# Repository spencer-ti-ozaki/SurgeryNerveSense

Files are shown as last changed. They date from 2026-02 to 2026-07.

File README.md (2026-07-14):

# NerveSense

**NerveSense** is a surgical proximity device designed to help surgeons detect and avoid peripheral nerves during incision. It estimates the distance between a surgical probe and a nearby nerve in real time, displaying the result on an LCD screen. Link for demo video: https://youtu.be/kSlPQVkup6I

> **Disclaimer:** NerveSense is a proof-of-concept prototype developed as a university engineering project. It is not approved for clinical use, and has only ever been tested on a tissue phantom with a controlled nerve analog — never on a live nerve or living tissue. See [TESTING.md](TESTING.md).

### Documentation

| File | What's in it |
|---|---|
| **README.md** | Overview, subsystems, hardware (this file) |
| [THEORY.md](THEORY.md) | Operating principle & the physics of the distance estimate |
| [TESTING.md](TESTING.md) | **How it was validated** — nerve analog, tissue phantoms, data, results, scope |
| [RESEARCH.md](RESEARCH.md) | Open questions & next experiments (for collaborators / follow-on work) |
| [USAGE.md](USAGE.md) | Step-by-step operating instructions |
| [WIRING.md](WIRING.md) | Full wiring reference and pinout |

---

## The Problem

Peripheral nerve injuries (PNIs) affect 13–23 people per 100,000 annually in the US, with 8–25% caused directly by medical procedures. Full recovery occurs in only 5.1% of cases. Current nerve-detection technologies (ultrasound, IONM, fluorescent markers) lack real-time, unambiguous proximity sensing — NerveSense addresses this gap.

---

## How It Works

NerveSense is divided into four subsystems: **Signaling → Receiving → Calculating → Displaying.**

```
┌─────────────────────────────────────────────────────────┐
│                    NerveSense System                    │
│                                                         │
│  [TENS Pads] ──► [L298N Driver] ──► Stimulates tissue  │
│       ▲                                    │            │
│  12V Boost                         Compound Action      │
│  (XL6009)                          Potential (CAP)      │
│                                            │            │
│  [Scalpel Electrode (S+)] ◄────── tissue response       │
│  [Reference Electrode (S-)]                │            │
│            │                               │            │
│            └──────► [AD620 Amplifier] ─────┘            │
│                          │ (100x gain)                  │
│                          ▼                              │
│                  [Raspberry Pi Pico]                    │
│                  ADC reads voltage                      │
│                          │                              │
│                          ▼                              │
│                   Distance calculation                  │
│                   d = 20 × e^(−7.21 × ΔV)              │
│                          │                              │
│                          ▼                              │
│                    [20×4 LCD Display]                   │
│             Row 1: Proximity warning                    │
│             Row 2: Distance (cm)                        │
│             Row 3: Voltage                              │
│             Row 4: Delta Voltage                        │
└─────────────────────────────────────────────────────────┘
```

---

### 1. Signaling

Two **TENS unit electrode pads** are placed on the patient's skin over the surgical site. An **L298N motor driver** switches these pads on and off at **20 Hz** — the clinically established frequency for eliciting a Compound Action Potential (CAP) from a nerve. A **XL6009 DC-DC boost module** steps the supply up to **12V** to compensate for the ~40% voltage drop across the pads and skin, ensuring at least 5V reaches the tissue.

A **grounding electrode** was added to the signaling unit to prevent charge buildup in the tissue (which would otherwise behave like a capacitor and corrupt the signal).

### 2. Receiving

When a stimulated nerve fires, it produces a CAP — an AC electrical response with a peak voltage of ~100mV — that spreads outward through the surrounding tissue (volume conduction). The **scalpel probe (S+)** and a **reference electrode (S-)** measure the resulting voltage difference at the surgical site; the closer the probe is to the nerve, the larger the reading. (In bench testing this firing nerve was replaced by a controlled **nerve analog** — see [TESTING.md](TESTING.md) — and the physics of why amplitude encodes distance is in [THEORY.md](THEORY.md).)

Because 100mV is too weak for the Pico's ADC to read directly, the signal passes through an **AD620 instrumentation amplifier module** at a gain of 100×. A custom PCB with an INA333 amplifier and bandpass filter was also designed (using Altium Designer) to isolate the nerve's 20Hz signal — see `/PCB` for design files.

> **PCB Note:** The custom INA333 PCB is a more robust alternative to the AD620 module due to its integrated bandpass filter, which actively filters out non-nerve frequencies and reduces noise. However, if using the PCB, the RG resistor should be swapped to a **100 Ω resistor** to set the correct gain for this application. Additionally, the PCB in its present state includes **no voltage protection** — adding a clamping circuit or protection resistors before any further use is strongly recommended.

The electrodes are made from **silver wire coated in AgCl** (via reaction with bleach) to minimize capacitive interference — bare stainless steel was found to convert the tissue analogue into a capacitor, skewing readings.

### 3. Calculating

The Raspberry Pi Pico reads ADC samples every millisecond and computes:

- **`baseline`** — mean ADC reading captured at startup, with the device at rest (calibration period)
- **`avg_diff_volts`** — average voltage deviation from baseline over each 250ms window

Distance is estimated using an empirically derived exponential curve fitted to 10 data points (R² = 0.9321):

```
d = 20 × e^(−7.21 × avg_diff_volts)
```

The constants were fit on a tissue phantom; a separate physics-first (analytical) derivation gives the same exponential *shape* — both are documented in [THEORY.md](THEORY.md), and the calibration data behind them in [TESTING.md](TESTING.md).

**Proximity thresholds used for display warnings:**

| `avg_diff_volts` | Display Message |
|---|---|
| > 0.40 V | Close to Nerve |
| > 0.25 V | Medium to Nerve |
| > 0.10 V | Far to Nerve |
| ≥ 5V or 0V | Outside of Site |

### 4. Displaying

A **20×4 I2C LCD** shows:
- **Row 1:** Proximity warning (e.g., "Close to Nerve")
- **Row 2:** Distance in cm
- **Row 3:** Current voltage reading
- **Row 4:** Delta voltage (`avg_diff_volts`)

---

## Validation Summary

NerveSense was characterized on a **tissue phantom** (chicken breast, and agar/saline
gel) with a **nerve analog** (a copper wire driven at 110 mV / 20 Hz pulsed DC to
mimic a real ~100 mV CAP). It has **not** been tested on a live nerve.

| Metric | Result |
|---|---|
| Detection range | ~5 cm from the nerve analog |
| Distance accuracy | ±0.5 cm (0–5 cm range) |
| Empirical fit | R² = 0.9321 (10 calibration points) |
| Reliability | ~10% of samples show voltage spikes |

Full methodology, scope, and what this does/doesn't prove: **[TESTING.md](TESTING.md)**.

---

## Hardware Components

| Component | Role |
|---|---|
| Raspberry Pi Pico | Microcontroller / ADC |
| L298N Motor Driver (×2) | Nerve stimulation + testing |
| XL6009 DC-DC Boost | Step up to 12V for signaling |
| AD620 Amplifier Module | 100× signal amplification |
| 20×4 I2C LCD | Distance/voltage display |
| TENS Unit Contact Pads | Stimulating electrodes |
| Skintact Electrode Pads (×3) | Receiving electrodes |
| AgCl-coated Silver Wire | Low-capacitance electrode material |
| Custom PCB (INA333) | Bandpass filter + amplifier (see `/PCB`) |

---

## Repository Structure

```
SurgeryNerveSense/
├── CAD/              # STEP files for the scalpel probe, frame, lid, and enclosure
├── PCB/              # PCB design files (Altium), DWG, and design rule check
├── Code/             # MicroPython firmware for the Raspberry Pi Pico
├── README.md         # This file — overview
├── THEORY.md         # Operating principle & physics
├── TESTING.md        # Validation methodology, data, and results
├── RESEARCH.md       # Open questions & next experiments
├── USAGE.md          # Step-by-step operating instructions
└── WIRING.md         # Wiring reference and pinout
```

---

## Limitations & Future Work

- Requires recalibration for different tissue types
- ~10% of samples exhibit voltage spikes
- AgCl electrode coating degrades under sunlight and requires bleach re-coating between uses
- No emergency shut-off or voltage protection circuit

**Suggested future improvements:**
- Replace AD620 with INA333 + proper bandpass filter PCB
- Add voltage protection and emergency shut-off
- Improve UI for clinical accessibility

For the bigger research questions (testing on a real nerve, lock-in detection for
selectivity, calibration transfer) and proposed next experiments, see
**[RESEARCH.md](RESEARCH.md)**.

---

## Team

Developed by **Kona Burgess, Spencer Ozaki, Shreya Chellu, and Rui (Ryan) Geng** as part of the Cornerstone of Engineering II course at Northeastern University London (Spring 2026).

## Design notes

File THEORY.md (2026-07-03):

# NerveSense — Operating Principle & Theory

This document explains *why* NerveSense should work in principle, the physics
behind the distance estimate, and the assumptions that estimate rests on. For
how it was actually tested, see [TESTING.md](TESTING.md).

---

## 1. The intended biological mechanism

NerveSense is a **stimulate-and-record** proximity sensor:

1. **Stimulate.** TENS pads deliver a 20 Hz pulse train to the tissue around the
   surgical site. Clinical work shows ~20 Hz at a few volts of contact drive is
   sufficient to elicit a **compound action potential (CAP)** from a peripheral
   nerve (Ahn et al., 2025).
2. **Re-radiate.** A firing nerve is, electrically, a **propagating current
   source** inside a conductive volume (tissue). It sets up a potential field
   that spreads outward through the surrounding medium (volume conduction).
3. **Record.** A scalpel-mounted electrode (S+) and a distant reference (S−)
   measure the local potential of that field. The **closer the probe is to the
   nerve, the larger the recorded potential.**
4. **Convert.** Amplitude → distance via a calibrated curve.

The signal of interest is **phase-locked to the 20 Hz stimulus**, which in
principle separates "the nerve we are driving" from unrelated tissue noise.

---

## 2. Why amplitude encodes distance

In a conductive medium, the potential from a current source falls off with
distance from that source. The device leans on this monotonic relationship:
more voltage at the probe ⇒ closer to the source.

### Analytical sketch (the physics-first derivation)

Model the path between source and probe as a conductor whose resistance depends
on geometry:

```
R = ρ · L / A
```

- `ρ` — resistivity of the tissue (inverse of conductivity σ; muscle ≈ 0.15 S/m
  across-fiber)
- `L` — effective path length between source and probe (∝ distance)
- `A` — effective cross-sectional area of the conduction path

By Ohm's law the potential seen at the probe scales with this path resistance
for a given source current, and the instrumentation amplifier multiplies the
result by its gain `G`:

```
V_probe(measured) = G · I_source · R(L)  =  G · I_source · ρ · L / A
```

Because the *effective* `A` grows as the field spreads with distance while `L`
also grows, the measured amplitude **decays** as the probe moves away — and the
decay is steeper than linear, which is why an **exponential** fits the data far
better than a straight line. The full closed form (with the geometric
assumptions) is Appendix E of the project report.

> The analytical model gets the **shape** right but depends on `ρ`, geometry,
> and gain that are hard to pin down in messy tissue — which is why the shipped
> firmware uses the **empirical** fit instead (below).

### Empirical model (what actually ships)

```
d = 20 · e^(−7.21 · avg_diff_volts)          (d in cm)      R² = 0.9321
```

Fit to 10 measured (distance, voltage) points in a tissue phantom. See
[TESTING.md](TESTING.md) §5.

---

## 3. Signal conditioning (why the hardware looks the way it does)

The raw CAP is ~100 mV — far too small for the Raspberry Pi Pico's ADC and
buried in noise. The receive chain addresses this:

- **AD620 instrumentation amplifier, ×100** — measures the *difference* between
  S+ and S− (rejecting common-mode noise) and boosts it into the Pico's
  readable range.
- **Custom INA333 PCB + bandpass filter (alternative front end)** — designed to
  additionally reject everything outside the 20 Hz stimulation band. It needs a
  small DC bias to activate (the amplifier only turns on above ~0.1 V), solved
  with a voltage divider + 2.5 V pull-up. It ran reliably for ~3 weeks before
  both boards were destroyed; the AD620 module was the fallback for the demo.
- **AgCl-coated silver electrodes** — a bare stainless-steel electrode
  polarizes and turns the tissue interface into a **capacitor**, distorting the
  reading. Ag/AgCl is the standard **non-polarizable** bioelectrode; we made ours
  by coating silver wire via a bleach reaction.
- **Grounding electrode on the stimulator** — continuously discharges the tissue
  so the stimulus doesn't slowly charge the phantom like a capacitor.

---

## 4. Key assumptions (and where they can break)

| Assumption | Holds when… | Breaks when… |
|---|---|---|
| Source behaves like a clean line current source | Nerve fires synchronously to the stimulus | Weak/desynchronized firing; multiple nerves |
| Medium is roughly homogeneous & isotropic near the probe | Uniform phantom | Real tissue: fat/vessel/bone boundaries, anisotropy |
| Amplitude maps 1:1 to distance | Fixed source strength & geometry | Different nerve caliber/orientation → same amplitude, different distance |
| Calibration constants are valid | Same tissue type as calibration | New tissue conductivity → curve shifts (needs recalibration) |

These are exactly the questions a research collaboration would tackle — see
[RESEARCH.md](RESEARCH.md).

---

## 5. How this differs from existing nerve monitors

Commercial intraoperative systems (e.g. NuVasive/Globus NVM5, Medtronic NIM)
and stimulating dissectors work by **stimulating from the instrument and
recording the downstream muscle EMG** — proximity is inferred from the stimulus
current needed to evoke a twitch. NerveSense instead **stimulates proximally and
records the CAP directly at the probe.** That distinction is the potentially
novel part: it does not depend on an intact motor pathway or neuromuscular
junction, so in principle it could apply to sensory nerves and to nerves whose
target muscle isn't accessible. Whether that theoretical advantage survives
contact with a real nerve is the open research question.

---

## References

- Ahn, H.-Y., et al. (2025). *Bioresorbable, wireless dual stimulator for
  peripheral nerve regeneration.* Nature Communications 16(1).
  https://doi.org/10.1038/s41467-025-59835-7
- Zelenski, N.A., Oishi, T., Shin, A.Y. (2023). *Intraoperative Neuromonitoring
  for Peripheral Nerve Surgery.* J Hand Surg 48(4), 396–401.
  https://doi.org/10.1016/j.jhsa.2022.11.022

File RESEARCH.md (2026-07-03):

# NerveSense: Research Directions and Open Questions

*A brief for researchers evaluating NerveSense as a basis for further work.*

## Summary

NerveSense estimates the distance from a surgical probe to a peripheral nerve by
stimulating the nerve and recording its compound action potential (CAP) directly
at the probe, then mapping the recorded amplitude to distance. On a tissue
phantom driven by a controlled nerve analog, a ten-point empirical fit predicts
distance to within 0.5 cm over a 0 to 5 cm range (R² = 0.93) and produces a
real-time, unambiguous readout. The sensing physics has been demonstrated on the
bench. The two questions that determine whether the approach is clinically
meaningful, whether the relationship holds for a real excitable nerve and whether
the signal can be made selective, remain open and are the natural starting point
for a collaboration.

## Novelty

Existing intraoperative systems infer nerve proximity indirectly. Devices such as
the NuVasive/Globus NVM5, the Medtronic NIM, and stimulating dissectors deliver a
stimulus from the instrument and record the downstream muscle EMG; proximity is
read from the stimulus current required to evoke a twitch. That approach depends
on an intact motor pathway and neuromuscular junction, and it reports a muscle
response rather than a direct measurement at the tool.

NerveSense reverses the arrangement. Stimulation is applied proximally through
surface pads, and the CAP is recorded directly at the probe as a graded,
distance-dependent potential. Because the measurement is taken at the instrument
rather than at a muscle, the method does not require a motor endpoint, which in
principle extends it to sensory nerves and to nerves whose target muscle is
inaccessible. Recovering a continuous distance estimate from CAP amplitude, as
opposed to a binary "stimulus threshold crossed" signal, is the aspect most worth
investigating. Whether the graded relationship survives a biological source at
realistic signal levels is the central unknown.

## Established versus open

| Established on phantom | Open |
|---|---|
| Monotonic, fittable voltage-to-distance falloff in real tissue | Same behavior with a real excitable nerve as the source |
| 0.5 cm accuracy over 0 to 5 cm at calibrated conditions | Adequate SNR at a ~100 mV CAP through millimeters of real tissue |
| Real-time, unambiguous readout | Selectivity of the nerve against vessels and other conductors |
| Ag/AgCl electrodes and a grounding pad suppress capacitive artifacts | Transfer of the calibration across tissue types |

The full scope boundary is documented in [TESTING.md](TESTING.md).

## Proposed next experiments

1. Replace the copper nerve analog with a real nerve preparation. A frog sciatic
   nerve is the standard low-cost option, with an ex-vivo mammalian nerve as the
   next step. Repeating the distance-to-amplitude characterization on a
   biological source, and confirming whether the exponential relationship and the
   SNR both hold, is the single most informative test and the main capability a
   host lab's electrophysiology rig unlocks.
2. Add synchronous (lock-in) detection at the 20 Hz stimulation frequency. Only
   the stimulated nerve re-radiates in phase with the stimulus, so phase-sensitive
   detection should improve both SNR and selectivity, and stands on its own as a
   methods result. The current firmware reads raw amplitude only.
3. Quantify calibration drift across media. Running the protocol across agar
   batches of known conductivity (0.05 to 0.5 S/m) and across tissue types would
   measure how far the fitted constants move, and whether a normalization or
   self-calibration step removes the need to recalibrate per tissue.
4. Address amplitude ambiguity. A multi-electrode gradient probe, or the use of
   CAP latency rather than amplitude alone, could separate a small near source
   from a large far one.
5. Move to a medical-grade front end. The INA333 PCB with proper bandpass
   filtering, voltage protection, and an emergency shut-off is a prerequisite
   before any work involving a living subject.

## Prior art

- Triggered-EMG proximity systems: NuVasive/Globus NVM5 and Medtronic NIM.
- Patents on nerve-proximity instruments, including a scalpel with an integrated
  nerve sensor (US 5,928,158) and nerve proximity, direction, and pathology
  systems (US 9,931,077 and its family).
- Intraoperative neuromonitoring reviews (Zelenski et al., 2023) and
  peripheral-nerve stimulation parameters (Ahn et al., 2025).

Nerve-proximity sensing as a general goal is well established and patented. The
contribution here is the direct-CAP-recording mechanism and its quantitative
characterization, which the prior art does not cover in this form.

## Collaboration

The project provides a working, documented, low-cost bench prototype, spanning
hardware, firmware, CAD, and PCB, that already yields clean distance-to-voltage
data, together with a tightly scoped first experiment and a self-contained
methods angle in the lock-in approach. Advancing it draws on capabilities a host
lab is positioned to provide: an electrophysiology setup, nerve-preparation
protocols, and the ethics and tissue-use approvals required to test on a real
nerve.

*Maintained by the NerveSense team (Northeastern University London). Contact
details are in the repository and project report.*

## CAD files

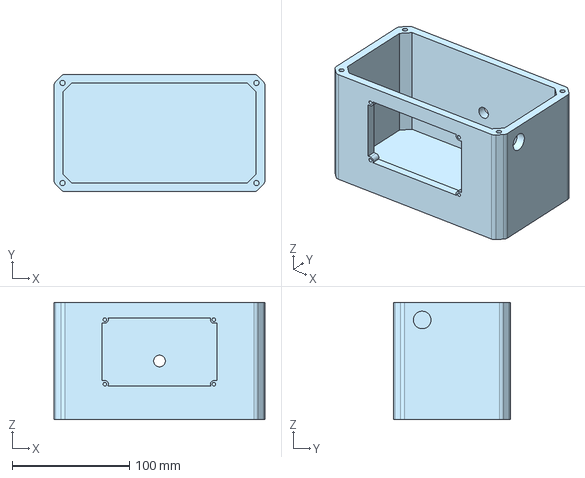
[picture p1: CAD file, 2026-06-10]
CAD/NerveSense-Frame.step
180.0 x 100.0 x 100.0 mm

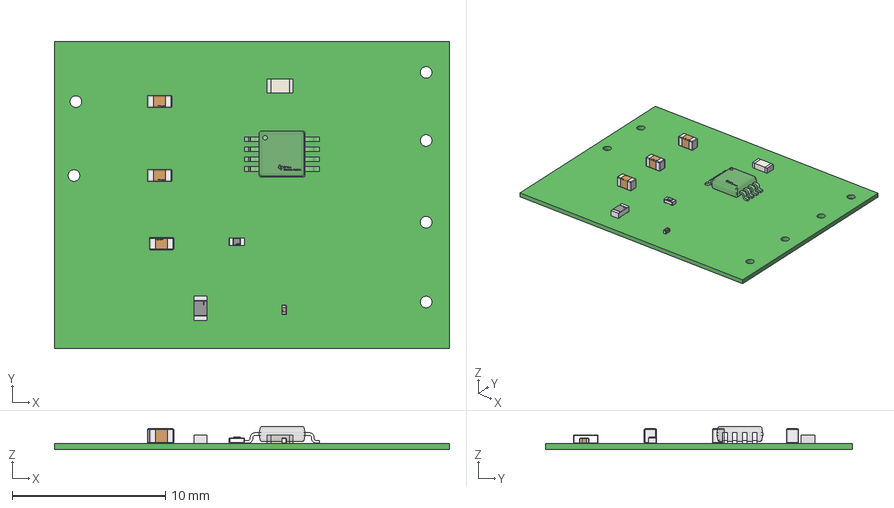
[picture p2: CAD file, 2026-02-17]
PCB/NerveSensePCBv0.2.1.step
25.8 x 20.1 x 1.51 mm
terminals x 5
logo x 5
BODY_MUA08A
LEAD_MUA08A x 8
Texas Instruments
circle
Extruded x 3
top
Sides
Core
Top
Vishay Logo

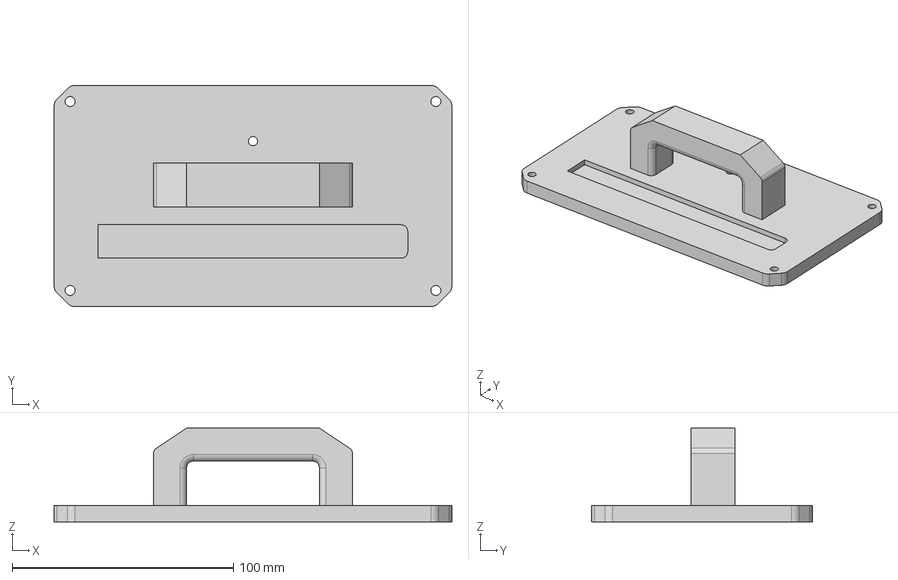
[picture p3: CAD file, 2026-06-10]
CAD/NerveSense-Lid.step
180.0 x 100.0 x 42.5 mm

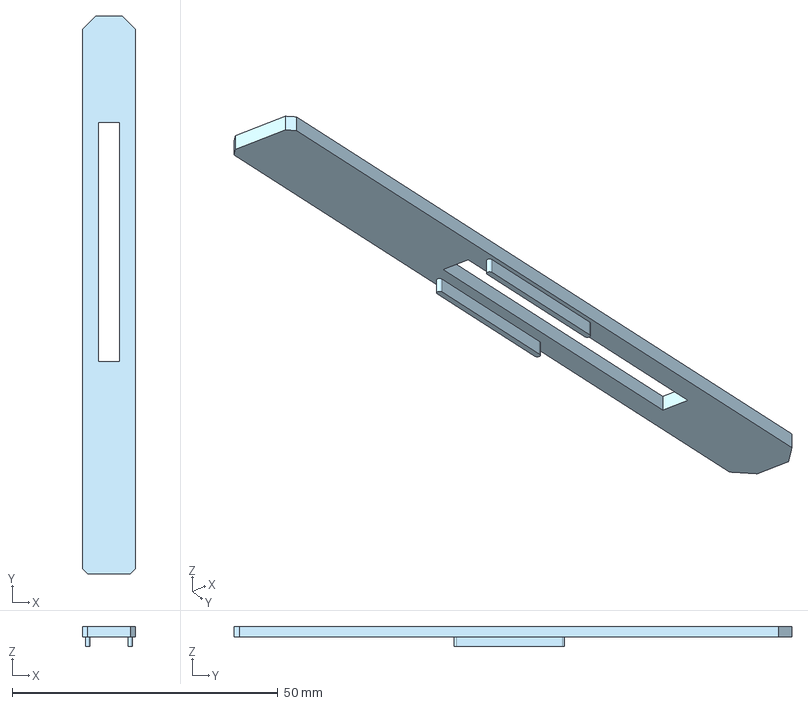
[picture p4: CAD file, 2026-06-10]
CAD/NerveSense-Scalpel Lid.step
10.0 x 105.0 x 3.85 mm

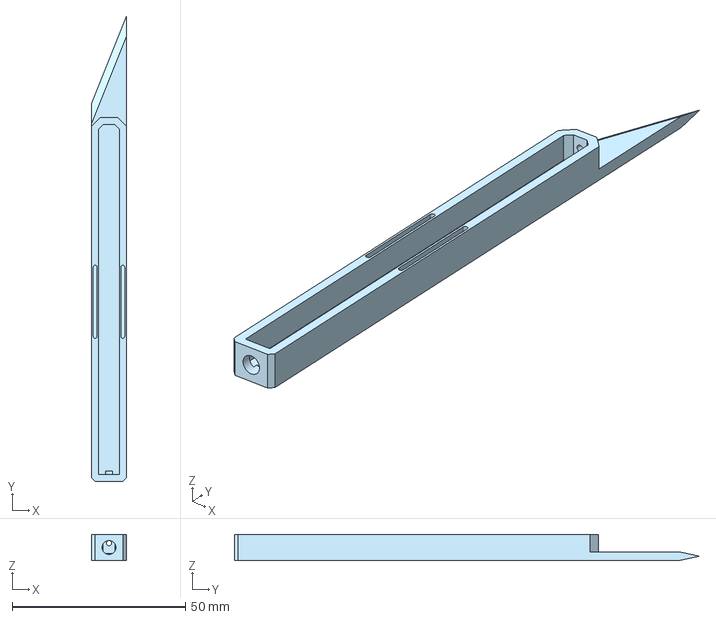
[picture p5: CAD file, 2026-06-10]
CAD/NerveSense - TestScalpelFrmae.step
10.0 x 134.1 x 7.50 mm

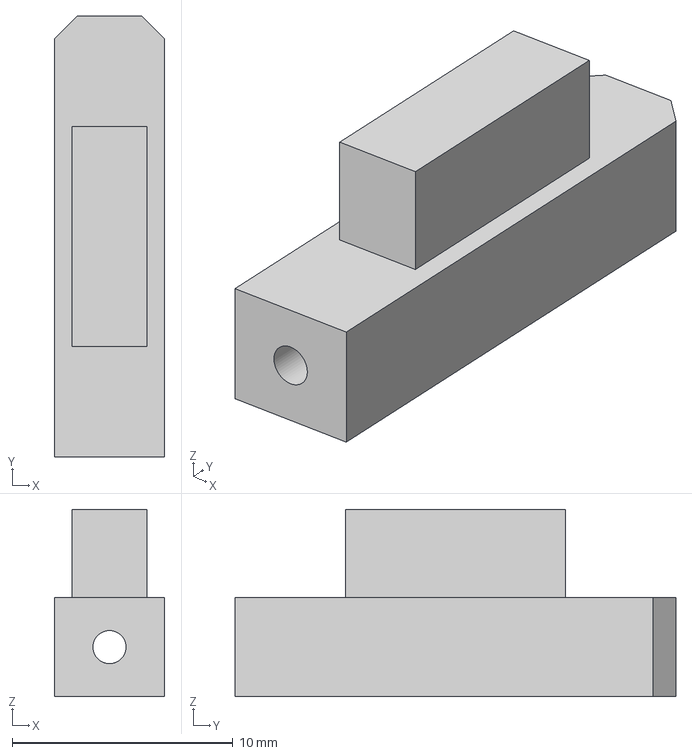
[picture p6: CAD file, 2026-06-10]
CAD/NerveSense - ScalpelSlider.step
5.00 x 20.0 x 8.50 mm

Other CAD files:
PCB/NerveSensePCBv0.2.1.DWG

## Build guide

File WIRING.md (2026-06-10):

# NerveSense — Wiring Reference

All wiring diagrams are based on the final working configuration of NerveSense v1.2. Pin numbers refer to **Raspberry Pi Pico GP pins**.

---

## System Overview

```
                        ┌─────────────┐
         12V Supply ───►│  XL6009     │──► 12V out
                        │  DC Boost   │
                        └─────────────┘
                               │
                               ▼
                        ┌─────────────┐         ┌──────────────────┐
                        │   L298N #1  │──OUT1───►│ Stimulating Pad  │ (TENS, on tissue)
                        │  (Signaling)│──OUT2───►│ Grounding Pad    │ (TENS, on tissue)
                        └─────────────┘         └──────────────────┘
                               ▲
                        ┌──────┴──────┐
                        │ Pico GP13   │ (ENA — PWM speed)
                        │ Pico GP14   │ (IN1)
                        │ Pico GP15   │ (IN2)
                        └─────────────┘

                        ┌─────────────┐         ┌──────────────────┐
                        │   L298N #2  │──OUT1───►│ Shock+ pad       │
                        │  (Testing)  │──OUT2───►│ Shock- pad       │
                        └─────────────┘         └──────────────────┘
                               ▲
                        ┌──────┴──────┐
                        │ Pico GP21   │ (IN3)
                        │ Pico GP19   │ (IN4)
                        └─────────────┘

  ┌──────────────────┐      ┌───────────────┐      ┌─────────────────┐
  │ Scalpel Electrode│──S+─►│  AD620 Module │─OUT─►│  Pico GP26      │
  │      (probe)     │      │  (100× gain)  │      │  (ADC0)         │
  │ Reference Electr.│──S-─►│               │      └─────────────────┘
  └──────────────────┘      └───────────────┘

                        ┌─────────────┐
                        │  20×4 LCD   │
                        │  (I2C)      │
                        └─────────────┘
                               ▲
                        ┌──────┴──────┐
                        │ Pico GP6    │ (SDA)
                        │ Pico GP7    │ (SCL)
                        │ 3.3V / GND  │ (power)
                        └─────────────┘
```

---

## 1. Signaling Unit — L298N #1 to TENS Pads

The signaling unit delivers biphasic pulses to the TENS pads at 20 Hz to elicit a Compound Action Potential (CAP) from nearby nerves.

```
  Raspberry Pi Pico          L298N Motor Driver #1        Electrodes
  ─────────────────          ─────────────────────        ──────────
  GP13 (PWM) ──────────────► ENA                          
  GP14       ──────────────► IN1          OUT1 ──────────► Stimulating TENS Pad
  GP15       ──────────────► IN2          OUT2 ──────────► Grounding TENS Pad
  GND        ──────────────► GND
                             VCC ◄──────────────────────── 12V (from XL6009 boost)
```

> The grounding pad continuously discharges the tissue to prevent capacitive charge buildup, which would corrupt the receiver signal.

---

## 2. Power — XL6009 DC-DC Boost Module

The XL6009 steps an input supply (e.g., a USB power bank or 5V rail) up to 12V to overcome the ~40% voltage drop between the motor driver and the TENS pads.

```
  Input Supply              XL6009 Boost Module         L298N VCC rails
  ────────────              ───────────────────         ───────────────
  5V  ─────────────────────► VIN+                       
  GND ─────────────────────► VIN−         VOUT+ ───────► L298N #1 VCC
                                          VOUT− ───────► L298N #1 GND
                                          VOUT+ ───────► L298N #2 VCC
                                          VOUT− ───────► L298N #2 GND
```

---

## 3. Receiver — Electrodes to AD620 to Pico ADC

The AD620 differential amplifier measures the voltage difference between the scalpel probe and the reference electrode, boosting the ~100mV nerve signal by 100× before the Pico reads it.

```
  Electrodes              AD620 Module              Raspberry Pi Pico
  ──────────              ────────────              ─────────────────
  Scalpel (S+) ─────────► IN+                       
  Reference (S−) ───────► IN−          OUT ────────► GP26 (ADC0)
                           VS+ ◄───────────────────── 3.3V
                           VS− ◄───────────────────── GND
                           REF ◄───────────────────── GND
```

**Gain setting:** The AD620 gain is set by the RG resistor between pins 1 and 8:

```
  Gain = 1 + (49.4kΩ / RG)
  
  For 100× gain:  RG ≈ 499 Ω
```

> If using the **custom INA333 PCB** instead of the AD620 module, swap the RG resistor to **1000 Ω** and add voltage protection before connecting. See `/PCB` for the PCB design files.

---

## 4. Electrode Placement on Tissue

```
  Surgical Site (cross-section view)
  ───────────────────────────────────────────────────────────
  
  ══════════════════ Skin Surface ══════════════════════════
  
  [Grounding Pad]──────────────────────[Stimulating Pad]
       │                                      │
       │         · · · · ·(nerve)· · · ·     │
       │                                      │
       └──────── tissue ──────────────────────┘
                               ▲
                         [Scalpel Probe (S+)]   ← surgeon probes here
  
  [Reference Electrode (S−)] placed far from incision point
  ───────────────────────────────────────────────────────────
```

- **Grounding pad** — flat on skin, over surgical site
- **Stimulating pad** — flat on skin, near incision area
- **Reference electrode (S−)** — far end of surgical site, away from incision
- **Scalpel probe (S+)** — the conductive scalpel blade itself, inserted into incision

---

## 5. LCD Display — I2C

```
  Raspberry Pi Pico          20×4 I2C LCD (address 0x27)
  ─────────────────          ───────────────────────────
  GP6  (SDA) ──────────────► SDA
  GP7  (SCL) ──────────────► SCL
  3.3V       ──────────────► VCC
  GND        ──────────────► GND
```

---

## 6. Full Pin Reference

| Pico GPIO | Function | Connected To |
|---|---|---|
| GP6 | I2C SDA | LCD SDA |
| GP7 | I2C SCL | LCD SCL |
| GP13 | PWM (ENA) | L298N #1 ENA |
| GP14 | Digital OUT (IN1)| L298N #1 IN1 |
| GP15 | Digital OUT (IN2)| L298N #1 IN2 |
| GP19 | Digital OUT (IN4)| L298N #2 IN4 |
| GP21 | Digital OUT (IN3)| L298N #2 IN3 |
| GP26 | ADC0 | AD620 OUT |
| 3.3V | Power | LCD VCC, AD620 VS+ |
| GND | Ground | All component grounds |

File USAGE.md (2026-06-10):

# NerveSense — Operating Instructions

> **Safety Notice:** NerveSense is a research prototype. Do not use on humans outside of a controlled experimental setting supervised by qualified medical personnel.

---

## What You'll Need

- NerveSense control unit (Raspberry Pi Pico + LCD + motor driver box)
- Scalpel/probe assembly with attached electrode wire (S+)
- 3× skin-contact electrodes:
  - 1× grounding electrode (TENS pad)
  - 1× stimulating electrode (TENS pad)
  - 1× reference electrode (S−), placed away from the incision site
- Power supply

---

## Setup & Operation

### Step 1 — Assemble the components
Connect the scalpel probe, electrodes, amplifier module, and LCD to the control unit. Ensure the AgCl electrode wires are properly coated — re-coat in bleach solution if the coating has degraded (dark tarnish indicates active coating; silver/bare wire indicates it needs re-coating). Keep electrodes away from direct sunlight, which degrades the AgCl coating.

### Step 2 — Place the grounding electrode
Attach the grounding electrode flat against the skin directly over the surgical site. This prevents charge from building up in the tissue during stimulation.

### Step 3 — Place the reference electrode
If available, place the reference electrode (S−) at the far end of the surgical site, well away from the intended incision point. This gives the amplifier a stable baseline to measure against.

### Step 4 — Place the stimulating electrode
Attach the stimulating TENS pad at the surgical site near the incision point. This pad delivers the electrical pulses that trigger a nerve response.

### Step 5 — Power on and calibrate
Turn on the NerveSense unit. The LCD will display **"Nervesense On"** and the device will spend the first few seconds measuring a baseline voltage. **Wait at least 5 seconds before probing** — moving the scalpel during this window will corrupt the baseline and produce inaccurate readings.

### Step 6 — Begin probing
Insert or advance the scalpel probe into the incision site. The LCD will update in real time:

| LCD Row | Displays |
|---|---|
| Row 1 | Proximity status (see below) |
| Row 2 | Estimated distance to nerve (cm) |
| Row 3 | Current voltage (V) |
| Row 4 | Delta voltage — ΔV from baseline (V) |

**Proximity status messages:**

| Message | Meaning |
|---|---|
| `Close to Nerve` | Probe is very close — proceed with extreme caution |
| `Medium to Nerve` | Moderate proximity — slow down |
| `Far to Nerve` | Nerve detected but distant |
| `Outside of Site` | Probe is outside the detectable range or signal lost |
| `No samples in 0.25s` | No valid signal received — check electrode contact |

---

## Tips

- If readings are erratic, check that all electrode pads have firm skin contact and that the AgCl wires are properly coated.
- The device is calibrated for a specific tissue type. Readings may drift if the probe moves to a region with significantly different tissue conductivity — power cycle and recalibrate if needed.
- The scalpel probe can be extended or retracted during probing; the device reads continuously.
- Distance estimates are accurate to approximately ±0.5 cm within a 0–5 cm range.

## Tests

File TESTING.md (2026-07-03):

# NerveSense — Testing & Validation

> **Read this first if you want to know *how we know NerveSense works*.** Every
> performance number in the README comes from the bench experiments described
> here. NerveSense has **never been tested on a live nerve or living tissue** —
> all validation to date used a controlled *nerve analog* inside a *tissue
> phantom*. This is deliberate (see [Ethics & Safety](#ethics--safety)), and it
> defines exactly what has and has not been proven.

---

## 1. Why a phantom?

We had no access to live nerves, animal models, or ex-vivo nerve preparations,
and our team contract explicitly ruled out testing on any organism. To develop
and characterize the device we therefore built a two-part physical model:

1. A **nerve analog** — a controllable electrical source standing in for a
   firing nerve.
2. A **tissue analog (phantom)** — a conductive medium standing in for the
   volume of tissue between the nerve and the probe.

This lets us vary "distance to nerve" precisely and repeatably, which a real
surgical field never would.

---

## 2. The nerve analog

A **bare copper wire** was embedded in the tissue phantom and driven with:

| Parameter | Value | Rationale |
|---|---|---|
| Amplitude | **110 mV** | Matches the ~100 mV peak of a real compound action potential (CAP) |
| Frequency | **20 Hz** | Same frequency the signaling unit stimulates at; a real nerve re-fires in sync with the stimulus |
| Waveform | **Pulsed DC** | Biphasic pulsing approximates the AC waveform of a propagating CAP |

The wire acts as a **linear current source** inside the conducting medium. When
you stimulate a real nerve, the depolarizing nerve behaves (to first order) like
exactly this kind of line source re-radiating into the surrounding tissue — so
the analog reproduces the *field the probe would see*, without requiring live
excitable tissue.

> **Characterization note.** During curve-fitting we initially drove the analog
> at a **higher-than-physiological voltage** to get a clean, high-SNR
> distance–voltage relationship, then **stepped the amplitude down** toward the
> real ~100 mV CAP level. This was a deliberate choice from interim-demo
> feedback: establish the relationship first, then push it toward realism.

---

## 3. The tissue analog (phantom)

Two media were used over the course of the project:

| Medium | Notes |
|---|---|
| **Agar / saline gel** | Castable, homogeneous, tunable conductivity. A batch was mixed toward **~0.15 S/m** — the approximate conductivity of skeletal muscle measured *across* (transverse to) the muscle fibers. Convenient for repeatable geometry. |
| **Chicken breast** | Real biological tissue, heterogeneous and anisotropic, with conductivity close to human soft tissue. **Used for the final demonstration** because it was the most reliable and accessible. |

We settled on **chicken breast** for the demo. Agar/gel was used earlier for
controlled, repeatable trials.

> ⚠️ **Data-availability caveat.** The quantitative results from the
> **0.15 S/m agar-saline gel** runs may **not have been captured/published**
> alongside the chicken-breast data. Treat the agar figures as *indicative*
> until the raw sheets are located and added to this repo. If you have them,
> drop the CSV/spreadsheet in a `data/` folder and update this file.

---

## 4. Measurement setup

```
   [L298N #1] --20 Hz--> [Stimulating TENS pad] ─┐
                                                 │   (in a real patient this
                                                 │    would fire the nerve)
   [Nerve analog: Cu wire @ 110 mV / 20 Hz] ─────┤   embedded at a known depth
                                                 │
   ================ tissue phantom ==============│=====
                                                 │
   [Scalpel probe S+] --+                        │
                        |--> [AD620 x100] --> [Pico ADC0 / GP26]
   [Reference S-]    ---+
```

The probe (S+) is advanced toward the analog at **measured distances**. At each
distance the firmware records the amplified differential voltage.

### What the firmware actually computes

From [`Code/NerveSenseTotal-v1.2.py`](Code/NerveSenseTotal-v1.2.py):

- **`baseline`** — mean ADC reading captured at startup (device at rest).
- **`avg_diff_volts`** — over each **250 ms** window, the mean of
  `(sample − baseline)` converted to volts. This is the signal that encodes
  distance.
- **`distance`** — `calc_distance(avg_diff_volts)` (see §5).

---

## 5. From voltage to distance — two approaches

We derived the distance estimate two independent ways and kept the one that
tracked the data best.

### Analytical (physics-first)
Starting from `R = ρL / A` (resistance of a conductor vs. length and
cross-section) and Ohm's law, combined with the instrumentation-amplifier gain,
we derived a closed-form relationship between probe–source distance and the
amplified voltage. See [THEORY.md](THEORY.md) for the derivation and its
assumptions. This gave the *right functional shape* but was sensitive to
phantom geometry and material constants.

### Empirical (data-first) — **used for the demo**
We sampled `avg_diff_volts` at **10 known distances** and fit an exponential:

```
d = 20 · e^(−7.21 · avg_diff_volts)          R² = 0.9321
```

where `d` is in cm and `avg_diff_volts` in volts. The empirical fit was the
**more accurate of the two** and is what ships in the firmware.

> The 10 raw calibration points live in **Figure 8** of the project report.
> They are **not yet in this repo as data** — adding a `data/calibration.csv`
> plus a plotting script is the single highest-value next commit for
> reproducibility.

---

## 6. Results

| Metric | Result |
|---|---|
| Detection range | Signal usable out to **~5 cm** from the analog |
| Distance accuracy | **±0.5 cm** within the 0–5 cm range |
| Goodness of fit | **R² = 0.9321** (10-point empirical exponential) |
| Reliability | **~10 %** of samples show voltage spikes/artifacts |

The device displayed distance and proximity warnings in real time on the LCD
with **no ambiguity** (a single monotonic reading), which was the core goal.

---

## 7. What this validates — and what it does *not*

**Validated (on the phantom):**
- A linear current source embedded in realistic conductive tissue produces a
  **monotonic, fittable voltage-vs-distance falloff** that the probe + AD620 +
  Pico chain can read in real time.
- The empirical exponential predicts distance to **±0.5 cm** over 0–5 cm in
  chicken breast, at the calibrated conditions.

**NOT yet validated (the open questions):**
- **A real excitable nerve as the source.** A copper wire is a far better
  conductor than an axon and is passively driven; a stimulated nerve produces a
  much weaker, biologically-shaped signal. Whether the SNR holds at ~100 mV
  through real tissue at surgical (mm) distances is untested.
- **Transferability of the calibration.** The constants `20` and `−7.21` are
  tied to one phantom, geometry, and tissue type. The device "requires
  recalibration for different tissue types" — quantifying that drift is future
  work.
- **Selectivity.** Everything conductive in tissue contributes to the field;
  the phantom can't show how well the nerve is distinguished from vessels or
  other structures. (See [RESEARCH.md](RESEARCH.md) for a proposed lock-in
  approach.)
- **Amplitude ambiguity.** A small source nearby and a large source farther
  away can read the same amplitude.

These gaps are not flaws in the result — they are the **scope boundary** of a
phantom study, and they define the next experiments in
[RESEARCH.md](RESEARCH.md).

---

## Ethics & Safety

NerveSense is a proof-of-concept and is **not approved for clinical use**. The
team deliberately restricted all testing to non-living phantoms. Any future
work with real nerve tissue must go through the appropriate ethics / animal-use
approvals and add hardware voltage protection and an emergency shut-off before
it goes anywhere near a living subject.

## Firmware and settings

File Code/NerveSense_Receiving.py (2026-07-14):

import math
from machine import ADC, Pin, PWM, I2C, Timer
from machine_i2c_lcd import I2cLcd
import time

# --- ADC setup ---
adc = ADC(26)  # GP26 = ADC0

# --- L298N: EN/IN1/IN2 ---
in1 = Pin(14, Pin.OUT)
in2 = Pin(15, Pin.OUT)
ena = PWM(Pin(13))  # ENA (PWM speed)
ena.freq(1000)
ena.duty_u16(0)  # start disabled

# Previous equation setup
'''Sigma = 2
A = (5)/10000
L = 12.5/100
v_applied = 0.25
v_wire = 0.1
Gain = 16
v_ref = 0

I = (v_applied*Sigma*A)/L'''

def calc_distance(avg_diff_volts):
    distance = 12.8*math.exp(-22.21*avg_diff_volts) # equation created by using testing data in Excel  
    return distance

def drive_nerve():
    # 1. both off
    in1.low()
    in2.low()
    ena.duty_u16(0)
    # 2. forward 10 ms
    in1.high()
    in2.low()
    ena.duty_u16(32768)   # 50% PWM ≈ 5 V drive
    time.sleep_ms(10)
    # 3. reverse 10 ms
    in1.low()
    in2.high()
    ena.duty_u16(32768)
    time.sleep_ms(10)

# --- Calibrate baseline (mean ADC at rest) ---
def calibrate_baseline(samples=1000):
    s = 0
    for _ in range(samples):
        s += adc.read_u16()
        time.sleep_ms(1)
    return s // samples

baseline = calibrate_baseline()
print("Baseline ADC =", baseline)

# --- Display Code ---
#Adjust pins here
i2c = I2C(1, sda=Pin(6), scl=Pin(7), freq=400000)
lcd = I2cLcd(i2c, 0x27, 4, 20)

update_flag = False

#set breakpoints here (calibrate voltage)
bkpsFar = 0.1
bkpsMed = 0.25
bkpsClose= 0.4

#exists so that other code can run during screen refreshes
def on_timer(t):
    global update_flag
    update_flag = True

tim = Timer(-1)
#Refresh rate set in variable period
tim.init(period=50, mode=Timer.PERIODIC, callback=on_timer)

lcd.clear()
lcd.putstr("Nervesense On")

def displayLCD(avg_v, avg_diff_v, distance, noResponse):
    global update_flag
    if update_flag:
        update_flag = False
        lcd.clear()
        lcd.move_to(0,2)
        lcd.putstr(f"Voltage: {avg_v}")
        lcd.move_to(0,3)
        lcd.putstr(f"Delta Voltage: {avg_diff_v}")
        lcd.move_to(0,0)
        if noResponse:
            lcd.putstr(f"No samples in 0.25s")
        elif avg_v >= 5 or avg_v == 0:
            lcd.putstr(f"Outside of Site")
        elif avg_diff_v > bkpsClose:
            lcd.putstr(f"Close to Nerve")
        elif avg_diff_v > bkpsMed:
            lcd.putstr(f"Medium to Nerve")
        elif avg_diff_v > bkpsFar:
            lcd.putstr(f"Far to Nerve")
        lcd.move_to(0,1)
        lcd.putstr(str(distance))

# --- Convert ADC counts to volts ---
def adc_to_volts(val):
    return val * 3.3 / 65535.0

# --- Main loop: 0.25 s averaging ---
while True:
    #Sleep 5 seconds so that there's time to adjust
    t_start = time.ticks_ms()

    # --- 0.25 s averaging window (250 ms) ---
    adc_sum = 0
    diff_sum = 0
    n = 0
    while time.ticks_diff(time.ticks_ms(), t_start) < 250:
        drive_nerve()   # biphasic pulse, non-alternating order
        val = adc.read_u16()
        diff = val - baseline
        adc_sum += val
        diff_sum += diff
        n += 1
        time.sleep_ms(1)

    if n > 0:
        avg_adc = adc_sum // n
        avg_diff = diff_sum // n
        # Convert to volts
        avg_voltage    = adc_to_volts(avg_adc)
        avg_diff_volts = adc_to_volts(avg_diff)
        read_d = calc_distance(avg_diff_volts)
        print(read_d)
        print("avg_ADC={}, avg_diff={}".format(avg_adc, avg_diff))
        print("avg_voltage = {:.6f} V".format(avg_voltage))
        print("avg_diff_volts = {:.6f} V".format(avg_diff_volts))
        if read_d < 5:
            displayLCD(avg_voltage, avg_diff_volts, read_d, False)
        else:
            displayLCD(avg_voltage, avg_diff_volts, "> 5", False)

    else:
        print("No samples in 0.25 s")
        displayLCD(0.0, 0.0, True)

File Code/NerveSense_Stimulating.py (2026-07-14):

import time

adc = machine.ADC(26) # GPIO 26
conversion_factor = 3.3 / 65535

# Define the GPIO pins connected to IN1 and IN2 of L298N
in1 = machine.Pin(21, machine.Pin.OUT)  # GPIO 21 (IN1)
in2 = machine.Pin(19, machine.Pin.OUT)  # GPIO 19 (IN2)

# Frequency of pulsed DC signal (20Hz)
frequency = 1  # 1 Hz for testing
period = 1 / frequency  # seconds

# Function to generate a pulsed DC signal
def pulsed_dc():
    # Continuously send 20Hz pulse
    while True:
        
        in1.high()  # Set IN1 HIGH
        in2.low()   # Set IN2 LOW
        time.sleep(period / 2)  # Wait for half the period (50% duty cycle)

        in1.low()   # Set IN1 LOW
        in2.high()  # Set IN2 HIGH
        time.sleep(period / 2)  # Wait for the other half of the period

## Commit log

2026-02-12 Added initial PCB and Schematic for receiver circuit
    [NerveSenseCircuit.dwg, NerveSensePCB.step]
2026-02-17 Delete NerveSense Electrical Project directory
    Needed updates
    [NerveSenseCircuit.dwg, NerveSensePCB.step]
2026-06-10 Create PCB Files
2026-06-10 Added CAD files for NerveSense Prototype
    [NerveSense - ScalpelSlider.step, NerveSense - TestScalpelFrmae.step, NerveSense-Frame.step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]
2026-06-10 Organize files into CAD and PCB folders
    [NerveSense - ScalpelSlider.step, NerveSense - TestScalpelFrmae.step, NerveSense-Frame.step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]
2026-06-10 Fix wording for grounding electrode instructions
2026-06-10 Add PCB note and wiring diagrams
2026-07-03 Add validation, theory, and research docs; correct README
    Document the testing methodology that was missing from the repo: the
    nerve analog (copper wire, 110 mV / 20 Hz pulsed DC), tissue phantoms
    (chicken breast + 0.15 S/m agar-saline gel), the empirical vs analytical
    distance models, and results (+/-0.5 cm over 0-5 cm, R^2=0.93).
    - TESTING.md: full validation methodology, data, and scope of what is
    and isn't proven (phantom only, never a live nerve).
    - THEORY.md: operating principle and the physics of the distance estimate.
    - RESEARCH.md: open questions and proposed next experiments.
    - README.md: honest phantom-validation framing, docs nav, validation
    summary, and cross-links.
    Co-Aut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
2026-07-03 Rewrite RESEARCH.md for a collaborator audience
    Address the reader rather than the team, drop the explicit pitch and class-project framing, reduce dash usage, and expand the direct-CAP-recording novelty discussion.
2026-07-07 Correct RG resistor value in PCB note
    Updated the RG resistor value in the PCB note from 1000 Ω to 100 Ω for correct gain settings.
